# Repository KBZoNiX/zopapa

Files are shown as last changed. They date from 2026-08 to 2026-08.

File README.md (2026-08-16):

# Zopapa

A two-wheel differential-drive line-following robot: Arduino Nano firmware, an 8-channel reflectance sensor array, and two custom KiCad PCBs.

Full functional specification: [`docs/FSD.html`](docs/FSD.html) · User manual (Spanish): [`docs/MANUAL.html`](docs/MANUAL.html)

## Features

- PD line-following control loop (proportional + derivative, ~500 Hz)
- Relay-feedback (Åström–Hägglund) autotune — computes and installs new gains from an induced oscillation
- EEPROM persistence of tuned speed/gains and sensor calibration — no need to re-sweep the line sensor on every power-cycle
- Serial/Bluetooth command interface for live tuning and telemetry (shared UART, 9600 baud)
- Optional turbine/vacuum subsystem for extra downforce, ramped proportionally to steering correction
- On-board HMI: pushbutton (short press starts/stops; long press saves gains to EEPROM or recalibrates the sensor, depending on DIP 4 — see FSD §7.1), 4-position DIP bank, status LED, buzzer

## Repo layout

```
src/zopapa/       Arduino sketch (zopapa.ino is the entry point)
src/libraries/    Vendored first-party libraries: DRV8833 (motor driver), ATRSensors (line sensor)
hardware/         KiCad PCB projects — main_pcb (Rapiduino) and line_sensor_pcb (ATR-8A)
docs/FSD.html     Functional Specification Document
docs/MANUAL.html  User manual (Spanish) — physical controls and BT/Serial commands
```

## Build

Requires [arduino-cli](https://arduino.github.io/arduino-cli/) with the `arduino:avr` core installed.

```sh
arduino-cli compile --fqbn arduino:avr:nano --libraries src/libraries src/zopapa
```

Arduino IDE: open `src/zopapa/zopapa.ino` directly, and copy or symlink `src/libraries/*` into your sketchbook's `libraries/` folder first.

## Flash

Most Nano (and clone) boards need the old-bootloader CPU variant:

```sh
arduino-cli compile --fqbn arduino:avr:nano:cpu=atmega328old --libraries src/libraries -u -p /dev/ttyUSB0 src/zopapa
```

If uploads fail with repeated `not in sync` errors, that's this — try the `atmega328old` variant. Requires your account to be in the `dialout` group (Linux).

## Command interface

Sent over Serial or Bluetooth (same UART, 9600 baud):

| Command | Function | Example |
|---|---|---|
| `S` | Start | `S` |
| `P` | Stop | `P` |
| `T` | Run autotune | `T` |
| `Vxxx` | Set speed | `V180` |
| `Kxxx` | Set KP | `K22.5` |
| `Dxxx` | Set KD | `D15.3` |
| `R` | Read current parameters | `R` |
| `L` | Load parameters from EEPROM | `L` |
| `W` | Save parameters to EEPROM | `W` |
| `Q` | Live sensor bar test | `Q` |
| `C` | Force a fresh sensor calibration sweep, then save it | `C` |
| `H` | Help | `H` |

See [`docs/FSD.html`](docs/FSD.html) for the full electrical interconnect, BOM, control-loop math, and known quirks.

## Notes

- Firmware comments and Serial output are in Spanish.
- No test suite.

## License

[MIT](LICENSE), except `src/libraries/ATRSensors`, which retains the CC BY-SA 3.0 notice of the Pololu QTRSensors code it's derived from (see the file header).

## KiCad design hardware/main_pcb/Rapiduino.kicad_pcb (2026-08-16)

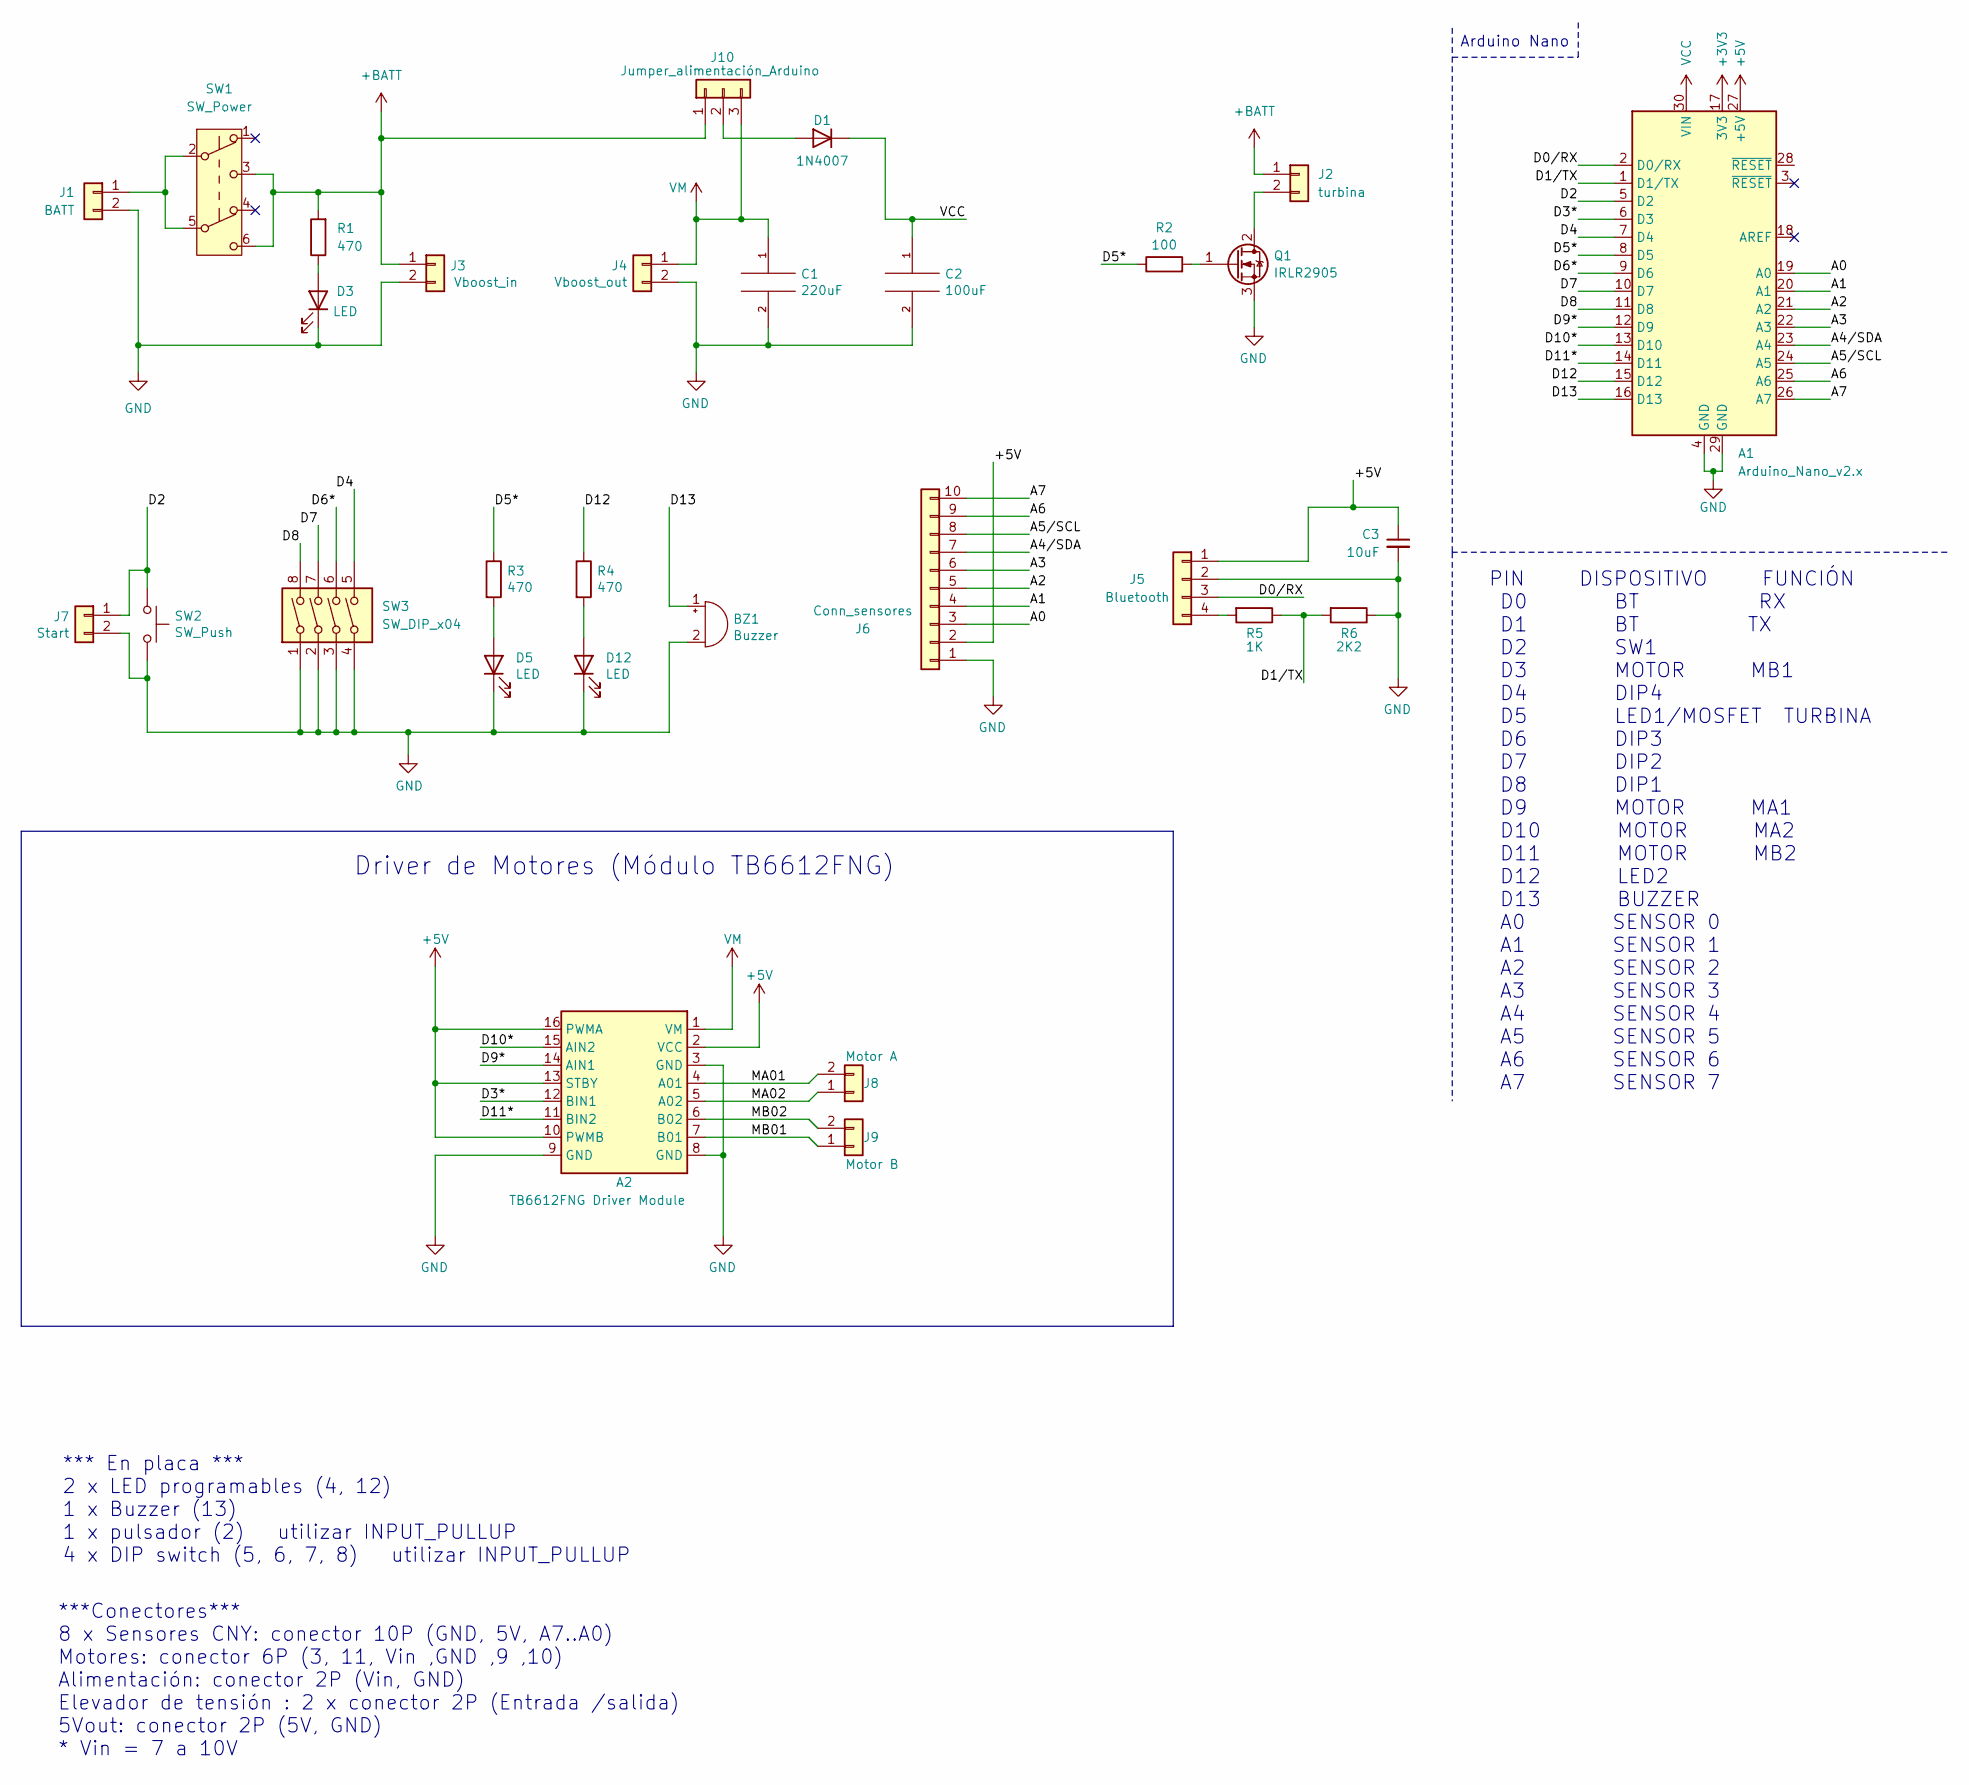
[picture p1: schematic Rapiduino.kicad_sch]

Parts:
A1: Arduino_Nano_v2.x; Arduino_Nano
A2: TB6612FNG Driver Module
BZ1: Buzzer; Buzzer_12x9.5RM7.6
C1: 220uF; CP_Radial_D6.3mm_P2.50mm
C2: 100uF; CP_Radial_D6.3mm_P2.50mm
C3: 10uF; C_1206_3216Metric_Pad1.33x1.80mm_HandSolder
D1: 1N4007; D_DO-41_SOD81_P7.62mm_Horizontal
D3, D5, D12: LED; LED_1206_3216Metric_Pad1.42x1.75mm_HandSolder
J1: BATT; PinHeader_1x02_P2.54mm_Vertical
J2: turbina; PinHeader_1x02_P2.54mm_Vertical
J3: Vboost_in; PinHeader_1x02_P2.54mm_Vertical
J4: Vboost_out; PinHeader_1x02_P2.54mm_Vertical
J5: Bluetooth; PinSocket_1x04_P2.54mm_Vertical
J6: Conn_sensores; PinHeader_1x10_P2.54mm_Vertical
J7: Start; PinHeader_1x02_P2.54mm_Vertical
J8: Motor A; PinHeader_1x02_P2.54mm_Vertical
J9: Motor B; PinHeader_1x02_P2.54mm_Vertical
J10: Jumper_alimentación_Arduino; PinHeader_1x03_P2.54mm_Vertical
Q1: IRLR2905; TO-252-2
R1, R3, R4: 470; R_0805_2012Metric_Pad1.20x1.40mm_HandSolder
R2: 100; R_0805_2012Metric_Pad1.20x1.40mm_HandSolder
R5: 1K; R_0805_2012Metric_Pad1.20x1.40mm_HandSolder
R6: 2K2; R_0805_2012Metric_Pad1.20x1.40mm_HandSolder
SW1: SW_Power; SW_Push_2P2T_Toggle_7x7mm
SW2: SW_Push; SW_PUSH_6mm
SW3: SW_DIP_x04; SW_DIP_SPSTx04_Slide_9.78x12.34mm_W7.62mm_P2.54mm

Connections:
+3V3: A1.17 (3V3)
+5V: A1.27 (+5V), A2.2 (VCC), A2.10 (PWMB), A2.13 (STBY), A2.16 (PWMA), C3.1, J5.1, J6.2
+BATT: J2.1, J3.1, J10.1, R1.2, SW1.3 (C), SW1.6 (C)
/A0: A1.19 (A0), J6.3
/A1: A1.20 (A1), J6.4
/A2: A1.21 (A2), J6.5
/A3: A1.22 (A3), J6.6
/A4/SDA: A1.23 (A4), J6.7
/A5/SCL: A1.24 (A5), J6.8
/A6: A1.25 (A6), J6.9
/A7: A1.26 (A7), J6.10
/D0/RX: A1.2 (D0/RX), J5.3
/D1/TX: A1.1 (D1/TX), R5.1, R6.2
/D2: A1.5 (D2), J7.1, SW2.1
/D3*: A1.6 (D3), A2.12 (BIN1)
/D4: A1.7 (D4), SW3.5
/D5*: A1.8 (D5), R2.1, R3.1
/D6*: A1.9 (D6), SW3.6
/D7: A1.10 (D7), SW3.7
/D8: A1.11 (D8), SW3.8
/D9*: A1.12 (D9), A2.14 (AIN1)
/D10*: A1.13 (D10), A2.15 (AIN2)
/D11*: A1.14 (D11), A2.11 (BIN2)
/D12: A1.15 (D12), R4.1
/D13: A1.16 (D13), BZ1.1 (-)
/MA01: A2.4 (A01), J8.2
/MA02: A2.5 (A02), J8.1
/MB01: A2.7 (B01), J9.1
/MB02: A2.6 (B02), J9.2
GND: A1.4 (GND), A1.29 (GND), A2.3 (GND), A2.8 (GND), A2.9 (GND), BZ1.2 (+), C1.2, C2.2, C3.2, D3.1 (K), D5.1 (K), D12.1 (K), J1.2, J3.2, J4.2, J5.2, J6.1, J7.2, Q1.3 (S), R6.1, SW2.2, SW3.1, SW3.2, SW3.3, SW3.4
unnamed: D1.2 (A), J10.2
unnamed: D3.2 (A), R1.1
unnamed: D5.2 (A), R3.2
unnamed: D12.2 (A), R4.2
unnamed: J1.1, SW1.2 (B), SW1.5 (B)
unnamed: J2.2, Q1.2 (D)
unnamed: J5.4, R5.2
unnamed: Q1.1 (G), R2.2
VCC: A1.30 (VIN), C2.1, D1.1 (K)
VM: A2.1 (VM), C1.1, J4.1, J10.3

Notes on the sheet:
*** En placa *** 2 x LED programables (4, 12) 1 x Buzzer (13) 1 x pulsador (2) utilizar INPUT_PULLUP 4 x DIP switch (5, 6, 7, 8) utilizar INPUT_PULLUP
Arduino Nano
Driver de Motores (Módulo TB6612FNG)
***Conectores*** 8 x Sensores CNY: conector 10P (GND, 5V, A7..A0) Motores: conector 6P (3, 11, Vin ,GND ,9 ,10) Alimentación: conector 2P (Vin, GND) Elevador de tensión : 2 x conector 2P (Entrada /salida) 5Vout: conector 2P (5V, GND) * Vin = 7 a 10V
PIN DISPOSITIVO FUNCIÓN D0 BT RX D1 BT TX D2 SW1 D3 MOTOR MB1 D4 DIP4 D5 LED1/MOSFET TURBINA D6 DIP3 D7 DIP2 D8 DIP1 D9 MOTOR MA1 D10 MOTOR MA2 D11 MOTOR MB2 D12 LED2 D13 BUZZER A0 SENSOR 0 A1 SENSOR 1 A2 SENSOR 2 A3 SENSOR 3 A4 SENSOR 4 A5 SENSOR 5 A6 SENSOR 6 A7 SENSOR 7

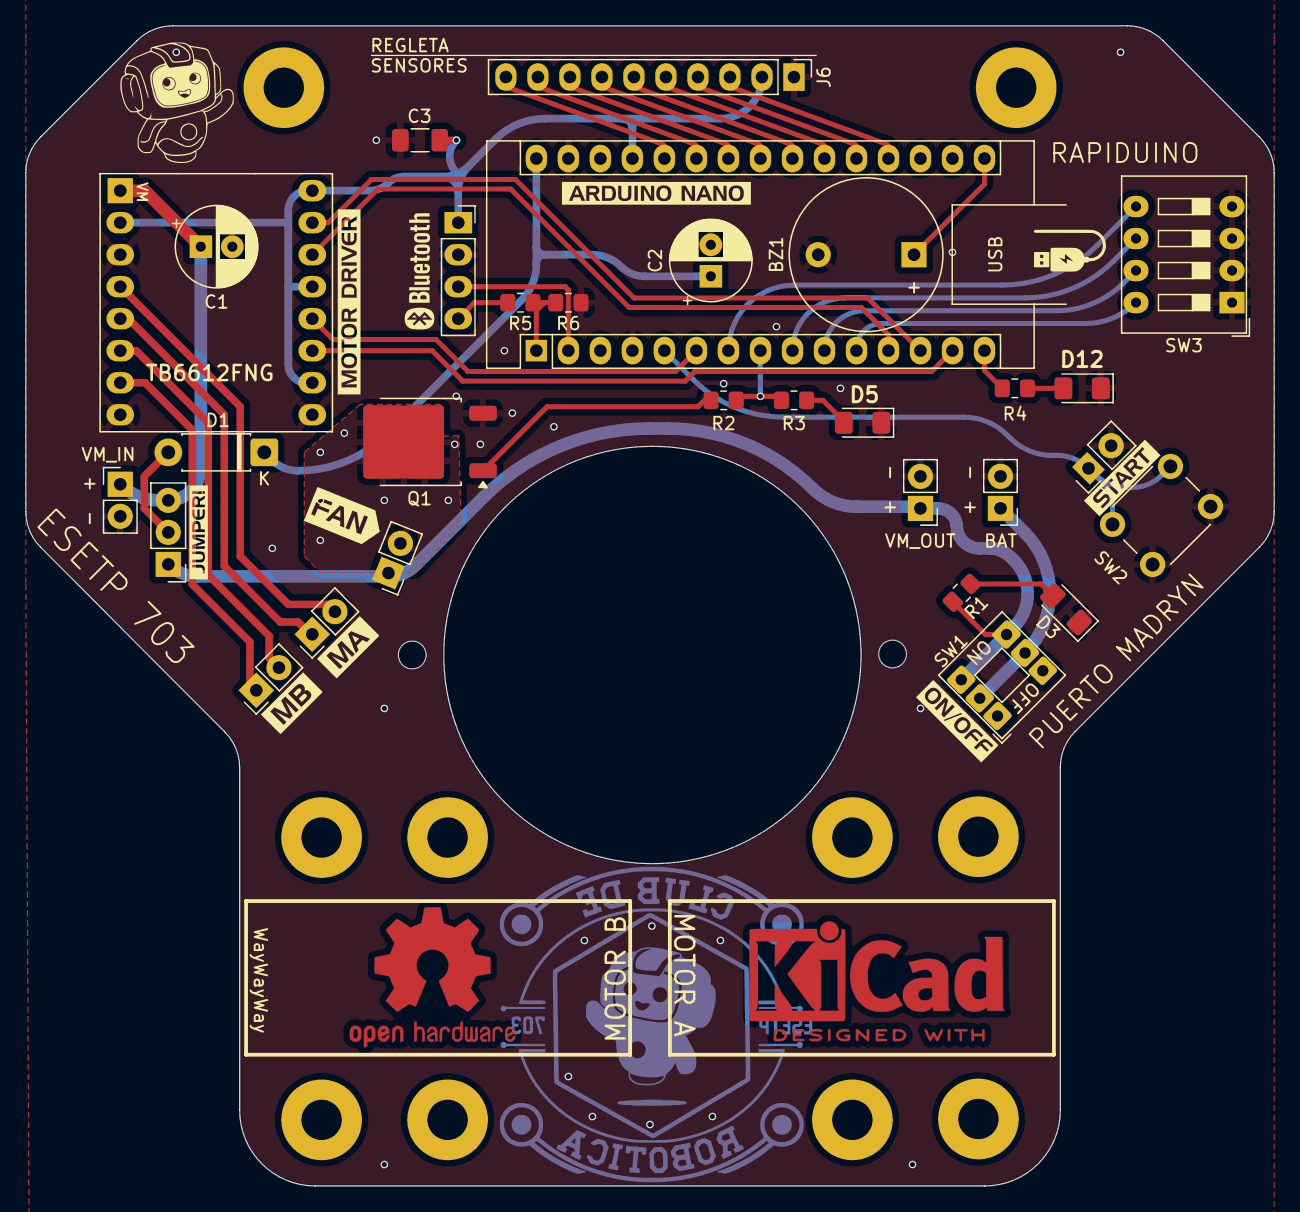
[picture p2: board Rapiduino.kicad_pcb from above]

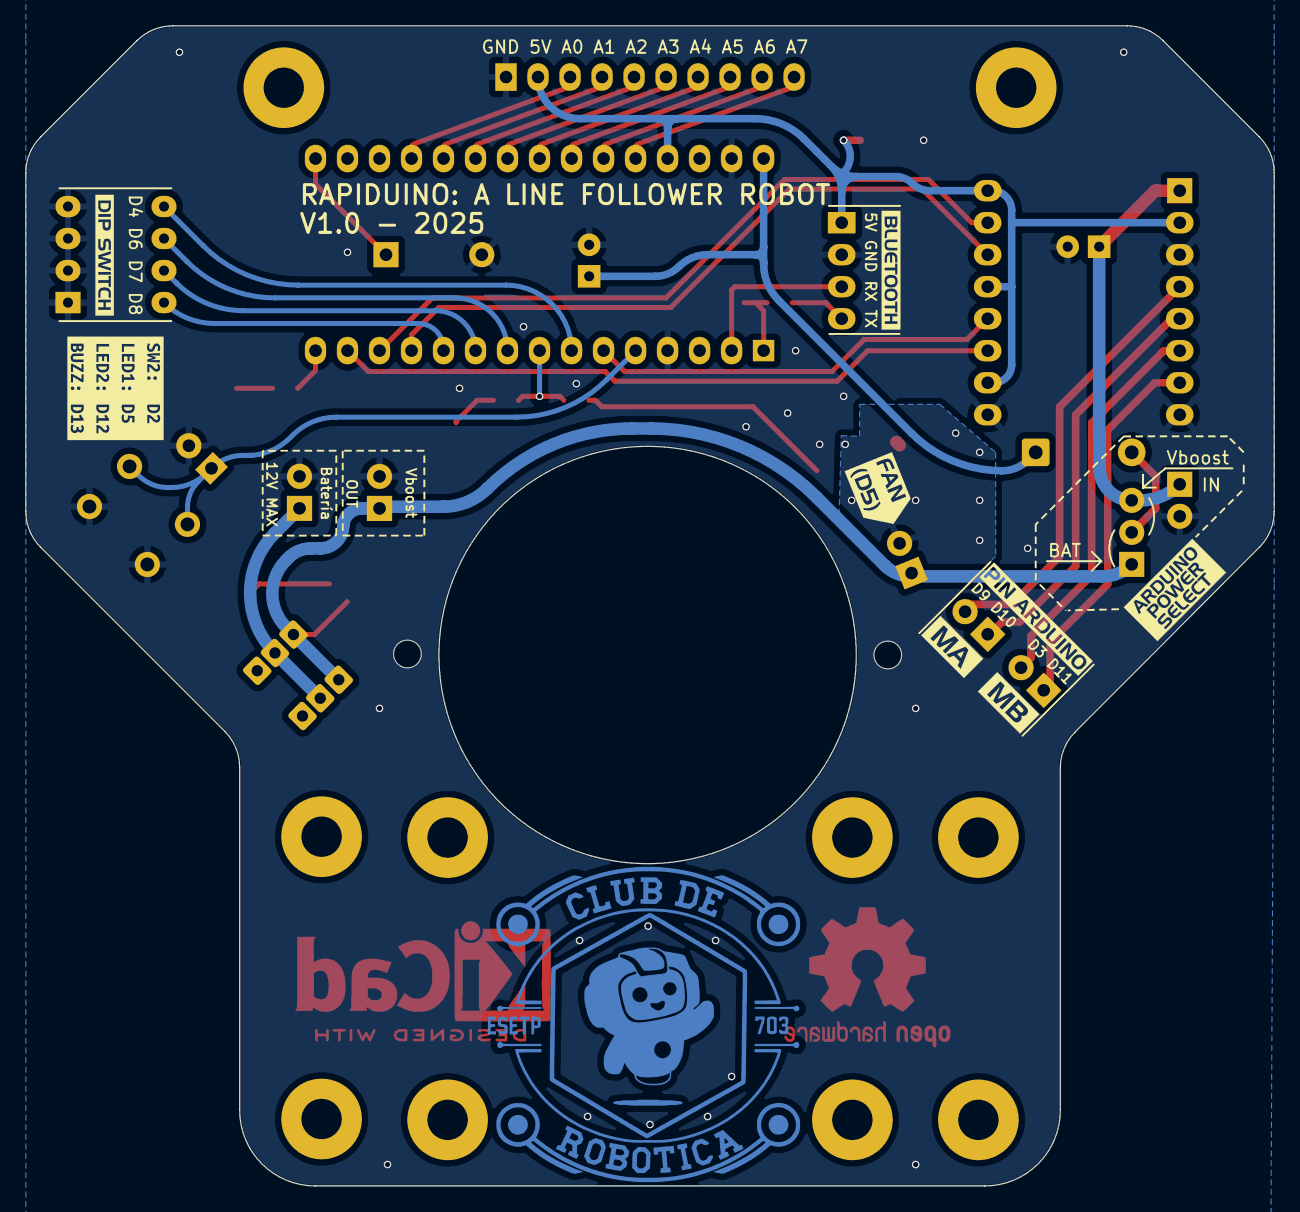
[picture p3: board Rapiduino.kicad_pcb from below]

Board: 2 copper layers, 99.1 x 92.1 mm, 46 parts (8 on the bottom side), 39 nets.

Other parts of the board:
kibuzzard-6850F7E0, kibuzzard-6850F7E0#2: G***; kibuzzard-6850F7E0
kibuzzard-6850F8CB: G***; kibuzzard-6850F8CB
kibuzzard-6850F811, kibuzzard-6850F811#2: G***; kibuzzard-6850F811
kibuzzard-6850FB1B: G***; kibuzzard-6850FB1B
kibuzzard-6850FB4B: G***; kibuzzard-6850FB4B
kibuzzard-68523F1B: G***; kibuzzard-68523F1B
kibuzzard-685101AF: G***; kibuzzard-685101AF
kibuzzard-685108A6: G***; kibuzzard-685108A6
kibuzzard-685108F3: G***; kibuzzard-685108F3
kibuzzard-685232D8: G***; kibuzzard-685232D8
kibuzzard-685241D4: G***; kibuzzard-685241D4
kibuzzard-685245CF: G***; kibuzzard-685245CF
kibuzzard-685246CF: G***; kibuzzard-685246CF
kibuzzard-6852314D: G***; kibuzzard-6852314D

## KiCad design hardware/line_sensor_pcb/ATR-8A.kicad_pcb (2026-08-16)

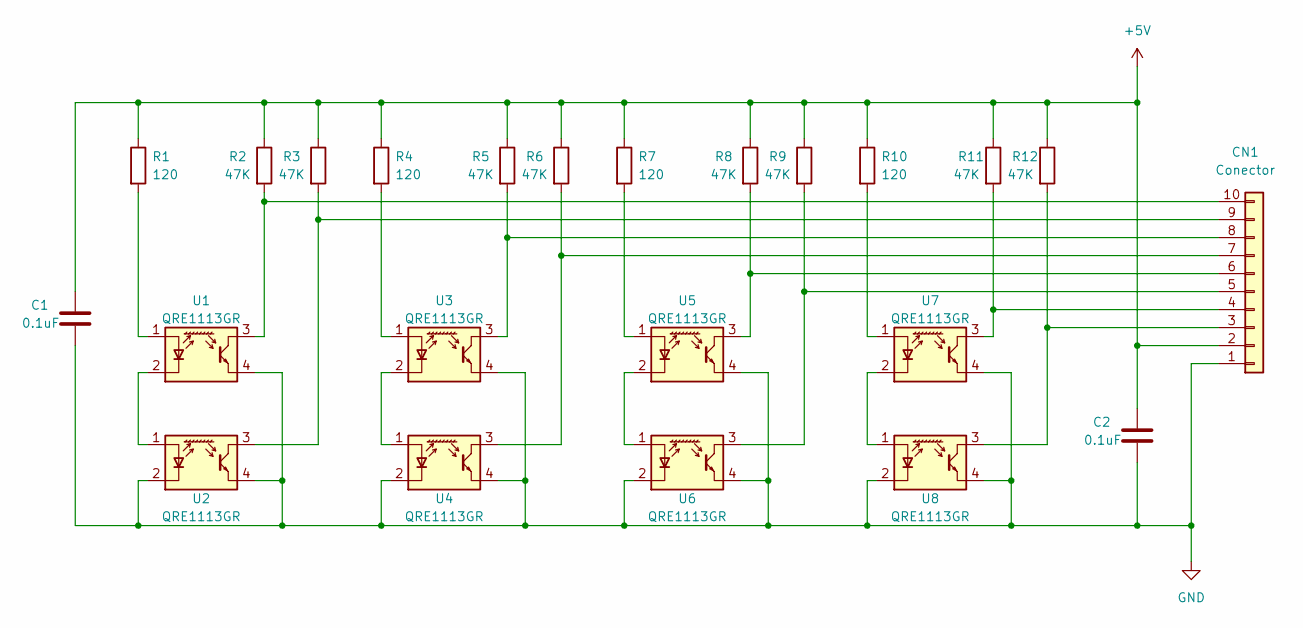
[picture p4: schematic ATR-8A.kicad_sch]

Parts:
C1, C2: 0.1uF; C_0805_2012Metric_Pad1.18x1.45mm_HandSolder
CN1: Conector; PinHeader_1x10_P2.54mm_Vertical
R1, R4, R7, R10: 120; R_0805_2012Metric_Pad1.20x1.40mm_HandSolder
R2, R3, R5, R6, R8, R9, R11, R12: 47K; R_0805_2012Metric_Pad1.20x1.40mm_HandSolder
U1, U2, U3, U4, U5, U6, U7, U8: QRE1113GR; OnSemi_CASE100CY

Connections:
+5V: C1.1, C2.1, CN1.2, R1.1, R2.1, R3.1, R4.1, R5.1, R6.1, R7.1, R8.1, R9.1, R10.1, R11.1, R12.1
GND: C1.2, C2.2, CN1.1, U1.4, U2.2 (K), U2.4, U3.4, U4.2 (K), U4.4, U5.4, U6.2 (K), U6.4, U7.4, U8.2 (K), U8.4
unnamed: CN1.3, R12.2, U8.3
unnamed: CN1.4, R11.2, U7.3
unnamed: CN1.5, R9.2, U6.3
unnamed: CN1.6, R8.2, U5.3
unnamed: CN1.7, R6.2, U4.3
unnamed: CN1.8, R5.2, U3.3
unnamed: CN1.9, R3.2, U2.3
unnamed: CN1.10, R2.2, U1.3
unnamed: R1.2, U1.1 (A)
unnamed: U1.2 (K), U2.1 (A)
unnamed: R4.2, U3.1 (A)
unnamed: U3.2 (K), U4.1 (A)
unnamed: R7.2, U5.1 (A)
unnamed: U5.2 (K), U6.1 (A)
unnamed: R10.2, U7.1 (A)
unnamed: U7.2 (K), U8.1 (A)

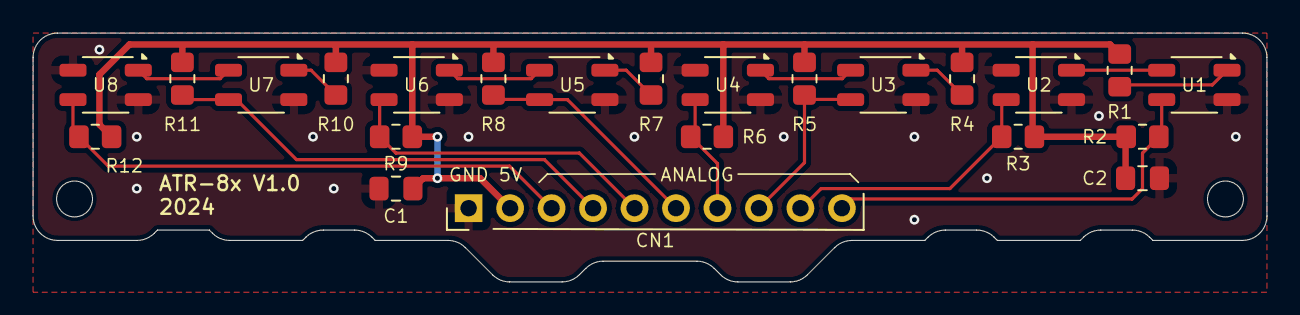
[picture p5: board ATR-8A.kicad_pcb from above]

Board: 2 copper layers, 75.6 x 15.2 mm, 23 parts (0 on the bottom side), 18 nets.

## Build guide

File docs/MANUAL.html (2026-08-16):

Manual de Usuario · Rev A

# ZOPAPA / Manual

Controles físicos y comandos por Bluetooth / puerto serie del robot seguidor de línea.

Idioma Español Alcance Uso diario: encendido, calibración, controles, comandos Referencia técnica completa docs/FSD.html

## 1. Antes de arrancar

Zopapa sigue una línea negra o blanca con una regleta de 8 sensores, y puede ajustar y guardar solo su propia calibración y sus parámetros de manejo (velocidad y ganancias) — no requiere una computadora para el uso diario, sólo para ajustes avanzados.

Al encender el robot con el interruptor principal, ocurre una de estas dos cosas:

- Si ya hay una calibración guardada de una sesión anterior, el robot la carga al instante (2 bips cortos) y queda listo para usar.
- Si no hay ninguna calibración guardada (primer uso, o después de un reinicio de fábrica), el robot pide un barrido manual: durante 3 segundos, con bips rápidos y el LED indicando que está "escuchando", hay que mover la regleta de sensores sobre la línea (de lado a lado, cruzándola varias veces) para que aprenda el contraste entre la línea y la superficie. Al terminar, guarda el resultado automáticamente — no hace falta repetir este paso en el próximo encendido.

Cuándo repetir la calibración Si cambia la pista, la iluminación del lugar, o la superficie, conviene recalibrar (sección 2.2 y 5) antes de correr — una calibración vieja puede hacer que el robot pierda la línea o reaccione de forma errática.

## 2. Controles físicos

### 2.1 Interruptor de encendido

Corta o conecta la alimentación de toda la placa. Al encender, el robot queda Detenido (motores y turbina apagados) hasta la primera pulsación del botón principal.

### 2.2 Pulsador principal

Acción | Condición | Efecto
Toque corto | Robot Detenido | Arranca. Si la llave DIP 3 está activada en ese instante, arranca además con la turbina.
Toque corto | Robot en marcha | Detiene el robot.
Toque largo (mantener ≥2 s) | Llave DIP 4 activada | Guarda en memoria la velocidad y ganancias (KP/KD) actuales. El robot queda Detenido al soltar.
Toque largo (mantener ≥2 s) | Llave DIP 4 desactivada | Repite el barrido de calibración de la regleta (igual que el comando C, sección 5). El robot queda Detenido al soltar.

El toque largo siempre termina Detenido Sea cual sea el estado del robot antes de mantener presionado el botón 2 segundos o más, al soltarlo queda Detenido — nunca arranca solo por haber hecho un toque largo.

### 2.3 Llave DIP (4 posiciones)

Posición | Función
1 | sin función Reservada; actualmente no hace nada.
2 | sin función Reservada; actualmente no hace nada.
3 | Activada: al arrancar con un toque corto, el robot enciende también la turbina de succión (velocidad proporcional a cuánto está corrigiendo el rumbo). Desactivada: arranca sin turbina.
4 | Doble función según el momento: al encender el robot, activada abre una ventana de 5 s para arrancar el AutoTune con el pulsador (sección 4); durante un toque largo del pulsador, activada guarda velocidad/ganancias y desactivada recalibra la regleta (ver 2.2).

### 2.4 Señales del LED y el zumbador

El robot no tiene pantalla: toda la retroalimentación es sonora (bips) o con el LED. Esta es la referencia completa:

Señal | Significa
1 bip corto + LED encendido (fijo) | El robot arrancó (marcha normal o con turbina).
3 bips cortos + LED apagado | El robot se detuvo.
2 bips cortos | Calibración cargada desde la memoria (se saltó el barrido manual).
2 bips + bips rápidos durante ~3 s | Barrido de calibración en curso — mover la regleta sobre la línea ahora.
2 bips largos, repitiéndose mientras se mantiene el botón | Guardando velocidad/ganancias en memoria (toque largo, DIP 4 activada).
5 bips largos | Arrancando el AutoTune.
2 bips cortos (al final del AutoTune) | AutoTune terminado con éxito — resultado sólo en memoria, ver sección 4.
1 bip largo | AutoTune falló (no detectó suficiente oscilación).

## 3. Uso típico paso a paso

1. Ubicar el robot sobre la pista
  Apoyar la regleta de sensores sobre o cerca de la línea antes de encender, si se va a hacer un barrido de calibración.
2. Encender
  Con el interruptor principal. Esperar la secuencia de arranque (sección 1) — 2 bips si cargó calibración guardada, o el barrido de 3 s si no.
3. (Opcional) Ajustar la llave DIP 3
  Activarla antes de arrancar si se quiere usar la turbina en esta corrida.
4. Arrancar
  Toque corto del pulsador. El robot debería seguir la línea de inmediato.
5. Detener
  Toque corto del pulsador en cualquier momento. El robot también se detiene solo si pierde la línea por más de un instante (parada de seguridad).
6. (Si hace falta) Recalibrar
  Con el robot Detenido: toque largo (≥2 s) con la llave DIP 4 desactivada, o el comando C por Bluetooth/Serie.

## 4. Ajuste automático (AutoTune)

El AutoTune calcula automáticamente las ganancias de corrección (KP/KD) haciendo oscilar al robot sobre la línea y midiendo la respuesta. Se puede iniciar de dos formas:

- Al encender: con la llave DIP 4 activada, el robot abre una ventana de 5 s (avisando por el puerto serie) para presionar el pulsador y arrancarlo.
- En cualquier momento, por Bluetooth/Serie: con el comando T (sección 5).

Durante la prueba (hasta 2 s) el robot corrige de un lado a otro de forma controlada — es recomendable hacerlo con el robot sobre una guía recta o con las ruedas levantadas la primera vez. Al terminar con éxito (2 bips cortos), instala las nuevas ganancias — pero sólo en memoria de trabajo.

El resultado del AutoTune no se guarda solo Para que las ganancias calculadas sobrevivan a un apagado, hay que guardarlas explícitamente: toque largo del pulsador con la llave DIP 4 activada, o el comando W por Bluetooth/Serie.

## 5. Comandos por Bluetooth / Serie

El robot acepta comandos de texto por el mismo puerto que se usa para programarlo por USB, y por el módulo Bluetooth conectado a la placa — cualquiera de los dos sirve, con los mismos comandos. Velocidad: 9600 baudios. Cada comando se envía terminado en Enter (nueva línea).

Comando | Función | Ejemplo
S | Arrancar (marcha normal — no activa la turbina aunque la llave DIP 3 esté activada) | S
P | Detener | P
T | Ejecutar AutoTune | T
Vxxx | Ajustar velocidad (0–255) | V180
Kxxx | Ajustar ganancia KP | K22.5
Dxxx | Ajustar ganancia KD | D15.3
R | Leer velocidad y ganancias actuales | R
L | Cargar velocidad/ganancias guardadas en memoria | L
W | Guardar la velocidad/ganancias actuales en memoria | W
Q | Modo prueba: muestra continuamente la lectura cruda de los 8 sensores. Para salir, presionar el pulsador físico. | Q
C | Recalibrar la regleta (barrido de 3 s, igual que el toque largo con DIP 4 desactivada) | C
H | Mostrar la lista de comandos | H

La mayoría de los comandos sólo se procesan con el robot Detenido Mientras está en marcha, el único comando que se acepta es P (Detener), por seguridad — los demás se ignoran hasta detenerlo.

## 6. Preguntas frecuentes

### El robot se detiene solo apenas arranca

Es la parada de seguridad por pérdida de línea: si la regleta no detecta la línea por un instante prolongado, el robot se detiene solo. Suele deberse a una calibración desactualizada — recalibrar (sección 2.2 o comando C) suele resolverlo.

### Cambié la velocidad con V pero no vi el efecto esperado en las curvas

La velocidad y las ganancias trabajan juntas — si se cambia mucho la velocidad sin volver a ajustar KP/KD (manualmente o con AutoTune), la corrección puede quedar desproporcionada para la nueva velocidad.

### Las posiciones 1 y 2 de la llave DIP no parecen hacer nada

Es correcto — están reservadas para uso futuro, pero el firmware actual no las usa.

### ¿Cómo sé si el AutoTune guardó los resultados?

No lo hace automáticamente (sección 4). Usar R por Bluetooth/Serie para ver las ganancias vigentes, y W (o el toque largo con DIP 4 activada) para guardarlas.

## 7. Referencia rápida

### Tarjeta resumen

Arrancar / Detener

Toque corto del pulsador

Guardar velocidad/ganancias

Toque largo (≥2 s) · DIP 4 activada

Recalibrar regleta

Toque largo (≥2 s) · DIP 4 desactivada — o comando C

Activar turbina en el próximo arranque

DIP 3 activada antes del toque corto

Arrancar AutoTune al encender

DIP 4 activada al encender, luego pulsador dentro de 5 s

Arrancar AutoTune en cualquier momento

Comando T

Guardar resultado del AutoTune

Comando W o toque largo con DIP 4 activada

Ver parámetros actuales

Comando R

Basado en el firmware en src/zopapa/ (Rev correspondiente a docs/FSD.html Rev H). Para el detalle técnico completo — electrónica, algoritmo de control, mapa de EEPROM — ver docs/FSD.html.

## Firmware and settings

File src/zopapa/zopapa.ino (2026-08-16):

// Sketch con Autotune (Relay) integrado

#include <DRV8833.h>     // Librería para controlar el driver de motores
#include <ATRSensors.h>  // Librería para utilizar la regleta de sensores
#include <EEPROM.h>




/*** CONFIGURACIÓN ***/
const int COLOR_LINEA = 1;  // Color de la linea a seguir (1: blanca / 0: negra):
const int EEPROM_AUTOLOAD = 0;   // Carga valores de EEPROM al arrancar
const int MAX_CICLOS_SIN_DETECTAR = 100; // Si no detecta linea para el robot



// constantes PID (ahora variables para permitir actualización por autotune):
// PROBADOS  SPEED    KP    KD
// P.CORTA   150      1.15  5
// P.CORTA   160      1.33  5.5
// P.CORTA   180      1.75  7.5
// P.CORTA   200      2     10
// P.CORTA   220      2.4   12
// P.CORTA   255      2.8   14

// byte SPEED = 130;       // 0..255
// float KP = 2.5 ;         // gains iniciales (serán sobrescritos por autotune si se ejecuta)
// float KD = 14 ;
byte SPEED = 100;       // 0..255
float KP = 2 ;         // gains iniciales (serán sobrescritos por autotune si se ejecuta)
float KD = 10 ;


// Limita la corrección máxima. Función (no const) porque SPEED puede cambiar
// en tiempo de ejecución (comando 'V', carga de EEPROM, autotune guardado).
int maxCorrection() {
  return SPEED * 2;
}


// Pines del Arduino utilizados
const int PULSADOR = 2;
const int TURBINA = 5;
const int LED = 12;
const int BUZZER = 13;
const int DIP_SW1 = 8;  // Incrementar velocidad
const int DIP_SW2 = 7;  // Incrementar KP y KD
const int DIP_SW3 = 6;  // Habilita turbina
const int DIP_SW4 = 4;  // Autotune

// Configuración de motores:
DRV8833 motorIzq(11, 3);  // pines del Arduino que utiliza el motor izquierdo
DRV8833 motorDer(9, 10);  // pines del Arduino que utiliza el motor derecho

// Configuración de la regleta de sensores:
const unsigned char SENSORES[] = { A0, A1, A2, A3, A4, A5, A6, A7 };  // Sensores de linea {pines}
const int NRO_SENSORES = sizeof(SENSORES);                            // Número de sensores de linea
ATRSensors Regleta(SENSORES, NRO_SENSORES);


/*** GLOBAL VARIABLES ***/
unsigned char sensor_values[NRO_SENSORES];
byte estado = 0;                            // 0 = Detenido; 1 = Normal; 2 = Turbina
int ultima_posicion = 0;
unsigned long lastLoopTime = 0;             // Guarda último valor de millis() para controlar el tiempo del loop
// Bluetooth
String btCommand = "";
bool btEnabled = true;
int ciclos_sin_detectar = 0;


/*** Autotune parameters ***/
// Amplitud de relé (magnitud de la corrección aplicada durante la prueba).
// Función (no const): debe reflejar el SPEED vigente al momento de ejecutar
// el autotune, no el valor por defecto con el que arrancó el sketch.
int relayAmplitude() {
  return SPEED * 0.5;
}
const int RELAY_SETTLE_CYCLES = 3;                // ciclos descartados (de estabilización)
const int RELAY_MEASURE_CYCLES = 6;               // ciclos usados para cálculo
const float AUTOTUNE_SAFETY_FACTOR = 0.9;         // Factor de seguridad para las constantes calculadas (Factor < 1 → más conservador / Factor = 1 → más agresivo)
const unsigned long AUTOTUNE_TIMEOUT_MS = 2000;   // seguridad: 25 s timeout
const unsigned long LOOP_MS = 2;                 // periodo de ejecución de la función correr() (ms)
const unsigned long AUTOTUNE_LOOP_MS = LOOP_MS;   // periodo de autotune (ms)



/**** SETUP ***/
void setup() {
  Serial.begin(9600);
  Serial.println(F("Iniciando..."));

  pinMode(PULSADOR, INPUT_PULLUP);
  pinMode(DIP_SW1, INPUT_PULLUP);
  pinMode(DIP_SW2, INPUT_PULLUP);
  pinMode(DIP_SW3, INPUT_PULLUP);
  pinMode(DIP_SW4, INPUT_PULLUP);
  pinMode(TURBINA, OUTPUT);
  pinMode(LED, OUTPUT);
  pinMode(BUZZER, OUTPUT);
    
  pararTurbina();
  motorIzq.begin();
  motorDer.begin();

  // Calibración de la regleta: usa la guardada en EEPROM si existe: si no,
  // requiere el barrido manual sobre la línea (y la guarda para la próxima).
  if (cargarCalibracion()) {
    Serial.println(F("Calibración cargada desde EEPROM."));
    beep(2, 80, 7);
  } else {
    calibrarRegletaManual();
  }

  // Carga los valores guardados en EEPROM
  if (EEPROM_AUTOLOAD) {
    leerConstantesPID();
  }
  
  // Entra en modo autotune
  if (digitalRead(DIP_SW4) == LOW) {
    confirmarInicioAutoTune();
  }

  indicar_estado(estado);

}  // FIN SETUP()


/**** CALIBRAR REGLETA (barrido manual) ***/
// Barrido manual de 3 segundos: mover la regleta sobre la línea. Guarda el
// resultado en EEPROM al terminar, para no repetirlo en el próximo arranque.
void calibrarRegletaManual() {
  // Descarta cualquier calibración ya cargada (EEPROM o un barrido previo en
  // esta misma sesión). ATRSensors::calibrate() sólo reinicia los límites a
  // sus valores centinela (255/0) cuando calibratedMinimum/Maximum están en
  // NULL; si no, sólo los ensancha. Sin este reseteo, un barrido "nuevo"
  // termina siendo una unión con el anterior en vez de reemplazarlo.
  if (Regleta.calibratedMinimum != 0) {
    free(Regleta.calibratedMinimum);
    Regleta.calibratedMinimum = 0;
  }
  if (Regleta.calibratedMaximum != 0) {
    free(Regleta.calibratedMaximum);
    Regleta.calibratedMaximum = 0;
  }

  Serial.println(F("Calibrar regleta..."));
  digitalWrite(LED, HIGH);
  beep(2, 100, 7);
  digitalWrite(LED, LOW);

  Serial.println(F("Calibrar regleta..."));
  for (int i = 0; i < 30; i++) {  // 3 segundos de calibración
    beep(1, 30, 7);
    long int ms = millis();
    while (millis() < ms + 100) {
      Regleta.calibrate();
    }
  }
  Serial.println(F("Calibrar regleta..."));

  guardarCalibracion();
}  // FIN calibrarRegletaManual()


/**** LOOP ***/
void loop() {

  if(digitalRead(PULSADOR) == LOW) {
    unsigned long t0 = millis();
    // espera y detecta si se mantiene pulsado
    while (digitalRead(PULSADOR) == LOW) {
      // Modo autotune, toque largo en PULSADOR (>= 2000 ms) guarda los valores nuevos:
      if (digitalRead(DIP_SW4) == LOW && millis() - t0 > 2000) {
        guardarConstantesPID(KP, KD, SPEED);
        estado = 1;  // fuerza que, al soltar el botón, el robot quede Detenido (ver debajo del while)
        digitalWrite(LED, HIGH);
        beep(2,500,8);
        digitalWrite(LED, LOW);
        delay(500);
      }
      // DIP_SW4 en HIGH (autotune no armado): toque largo (>= 2000 ms) recalibra la regleta:
      else if (digitalRead(DIP_SW4) == HIGH && millis() - t0 > 2000) {
        calibrarRegletaManual();
        estado = 1;  // idem: fuerza que, al soltar el botón, el robot quede Detenido
        delay(500);
      }
    }
    if (estado != 0) {
      estado = 0;
    } else if (digitalRead(DIP_SW3) == 0) {
      estado = 2;
    } else {
      estado = 1;
    }
    indicar_estado(estado);
  }

  if (estado != 0) {
    if (millis() - lastLoopTime > LOOP_MS) {
      correr();
      lastLoopTime = millis();
    }
    btListenStopOnly();
  } else {
    pararTurbina();
    motorIzq.stop();
    motorDer.stop();
    btListen();
  }
}  // FIN LOOP()


/**** INDICAR ESTADO ***/
void indicar_estado(byte status) {

  if (status != 0) {
    digitalWrite(LED, HIGH);
    beep(1, 100, 10);
  } else {
    digitalWrite(LED, HIGH);
    beep(3, 100, 7);
    digitalWrite(LED, LOW);
  }

  Serial.println(F("READY!"));
}  // FIN indicar_estado()

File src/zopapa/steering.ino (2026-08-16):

/**** CORRER ***/
// lee la posición sobre la regleta, calcula la corrección y la aplica a los motores
void correr(void) {

  // leo la posición:
  const int centro_de_linea = (NRO_SENSORES - 1) * 100 / 2;
  int posicion = centro_de_linea - Regleta.readLine(sensor_values, COLOR_LINEA);

  // verifica si el robot se salió de la línea y lo detiene
  if (abs(posicion) == centro_de_linea) {
    ciclos_sin_detectar += 1;
    if (ciclos_sin_detectar >= MAX_CICLOS_SIN_DETECTAR) {
      estado = 0;
      indicar_estado(estado);
      Serial.println(F("Fuera de Linea. Detenido"));
      return;
    }
  }
  else {
      ciclos_sin_detectar = 0;
  }

  // calculo la corrección:
  int correccion_pid = (KP * posicion) + (KD * (posicion - ultima_posicion));
    ultima_posicion = posicion;

  if (estado == 2) {
    actualizarTurbina(correccion_pid); // Actualiza velocidad turbina
  }

  // Aplico la corrección:
  if (correccion_pid > 0) {
    correccion_pid = min(correccion_pid, maxCorrection());
    motorIzq.speed(SPEED);
    motorDer.speed(SPEED - correccion_pid);
  } else {
    correccion_pid = max(correccion_pid, -maxCorrection());
    motorIzq.speed(SPEED + correccion_pid);
    motorDer.speed(SPEED);
  }

}  // FIN CORRER()

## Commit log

2026-08-16 Initial commit: reorganize firmware into src/, add CLAUDE.md and FSD
    Moves the Arduino sketch and vendored libraries (DRV8833, ATRSensors)
    under src/, keeps the two KiCad PCB projects under hardware/, and adds
    docs/FSD.html (functional specification) plus a root CLAUDE.md summarizing
    the project layout, build/flash commands, and non-obvious firmware facts.
    [ATR-8A.kicad_pcb, ATR-8A.kicad_sch, Rapiduino.kicad_pcb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]
2026-08-16 Fix MAX_CORRECTION/RELAY_AMPLITUDE freezing at default SPEED
    Both were const int, computed once at static-init time from SPEED's
    default value (100). Changing SPEED later at runtime (serial 'V', EEPROM
    autoload, a saved autotune run) never updated them, so the correction
    clamp, the turbine's suction mapping, and autotune's excitation amplitude
    all silently kept using the original default instead of the live speed.
    Converted both to functions that read SPEED live.
    [autotune.ino, turb.ino, zopapa.ino]
2026-08-16 Remove dead HMI helpers: presiono(), digitalToggle()
    Neither is called anywhere. presiono() also isn't a fit for loop()'s
    actual pushbutton handling, which needs hold-duration tracking it
    doesn't provide, so the fix is removal rather than wiring it in.
2026-08-16 Fix stale EEPROM address comments
    EEPROM_ADDR_SPEED's comment was copy-pasted from EEPROM_ADDR_KD ("KD
    (float ocupa 4 bytes)"), describing the wrong variable and the wrong
    type/size. The section header above it also only mentioned KP/KD even
    though the block stores the init flag and SPEED too.
    [autotune.ino]
2026-08-16 Add .gitignore and CI build check
    .gitignore covers Arduino build output and common KiCad backup
    artifacts. The GitHub Actions workflow compiles src/zopapa against the
    vendored libraries on every push/PR, using the same FQBN as local
    development, so build breakage gets caught automatically.
2026-08-16 Persist sensor calibration to EEPROM; add 'C' recalibrate command
    Sensor min/max calibration previously lived only in RAM, so every
    power-cycle required the full 3-second manual sweep even when KP/KD/SPEED
    autoloaded fine. Adds guardarCalibracion()/cargarCalibracion() (mirroring
    the existing PID EEPROM helpers) and a new serial/BT 'C' command to force
    a fresh sweep on demand. setup() now tries the saved calibration first and
    only falls back to the manual sweep when none is stored.
    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
2026-08-16 Document calibration EEPROM persistence and the C command
    Updates docs/FSD.html (Rev D: startup/calibration flow, EEPROM layout
    table, command table, and why the calibration flag uses a 2-byte magic
    marker instead of a single flag byte), README.md (command table, license
    section), and CLAUDE.md (key facts plus an EEPROM-flag convention note)
    to match the firmware change in ccca49f.
2026-08-16 Move EEPROM persistence out of autotune.ino into eeprom.ino
    autotune.ino was doing two unrelated jobs: the relay-feedback autotune
    algorithm itself, and all EEPROM read/write for both PID gains and sensor
    calibration. Splits the latter into its own file, mirroring the existing
    per-concern split (turb.ino, bt.ino). No behavior change — verified by
    compiling to an identical flash size (14300 bytes) before and after.
    Updates docs/FSD.html (Rev E) and CLAUDE.md to point at the new file, and
    fixes a doc bullet for extras.ino left stale since presiono()/
    digitalToggle() were removed earlier in this session.
    [autotune.ino, eeprom.ino]
2026-08-16 Move correr() out of zopapa.ino into steering.ino
    zopapa.ino mixed pin/config setup, the top-level state machine, and the
    actual PD steering algorithm in one file. Splits the control loop out,
    mirroring the existing per-concern layout (turb.ino, eeprom.ino). zopapa.ino
    is now orchestration only: config, setup(), loop(). No behavior change —
    verified by an identical compiled flash size (14300 bytes) before and after.
    Updates docs/FSD.html (Rev F) to match.
2026-08-16 Long-press + DIP_SW4 HIGH triggers a sensor recalibration
    Mirrors the existing long-press + DIP_SW4 LOW gesture (saves KP/KD/SPEED),
    giving DIP_SW4 a second meaning during a long hold: HIGH runs the same
    recalibration sweep as the 'C' serial command. Both branches set
    estado = 1 mid-hold so the button handler's post-release logic resolves
    to Stopped either way, regardless of the state before the hold started —
    same trick the existing save branch already relied on.
    While implementing this I traced that existing logic carefully and found
    docs/FSD.html §7.1 had it backwards: it claimed the long-press-save
    gesture "forces Running state," but estado = 1 mid-hold is deliberately
    overridden bac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
    [zopapa.ino]
2026-08-16 Fix calibration recalibration being cumulative instead of a true reset
    ATRSensors::calibrate() only resets calibratedMinimum/calibratedMaximum to
    their sentinel values (255/0) when those arrays are NULL — otherwise it
    only ever widens the existing range (min can shrink, max can grow, never
    the reverse). Since cargarCalibracion() had already populated those arrays
    from EEPROM before any manual recalibration ran, every "fresh" sweep via
    'C' or the new long-press gesture was actually a monotonic union with
    whatever was already loaded, not an independent measurement. A bad extreme
    picked up once (glare, dust) would stay baked in forever short of a full
    power-cycle.
    Caught by comparing two rea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
    [zopapa.ino]
2026-08-16 Add Spanish user manual (docs/MANUAL.html)
    Covers physical controls (power switch, pushbutton short/long-press
    semantics, the 4-position DIP bank including the DIP_SW4 dual meaning,
    the LED/buzzer feedback patterns) and the full Bluetooth/Serial command
    table, plus a step-by-step usage walkthrough, AutoTune instructions, an
    FAQ, and a one-page quick-reference card. Cross-referenced from README.md
    and CLAUDE.md.
